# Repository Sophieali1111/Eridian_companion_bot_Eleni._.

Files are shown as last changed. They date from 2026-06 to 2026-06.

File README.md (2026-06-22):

# Eridian_companion_bot_Eleni._. 
WATCHED PROJECT HAIL MARRY and wanted my own Eridian bot ROCKY ! Meet Eleni [ torch in Greek].

# What is this?
A robot has 5 legs and at least 6 degrees of freedom, has a OLED showing cute faces, temp and custom information. Can be linked to a controller but also could just be a desk top buddy with automatic responses to temp change, tap on the head and time. Would make your life a bit more cozy and whimsy:)))

# Features
- move through terrain
- Cute animated bitmoji
- tempreture and moisture
- react to headpats
- remote controlable (via iphone)

# How to use
Eleni can connect to mobile with its microo controller(ESP32DEV),It can tell you weather stats such as tempreture, moister- from DTH 22 modoule, and also tell you time, date, weekday via OLED screen. Screen switches to the diffrent stats with a headpat (touchpad mounted on top). Eleni expresses emotion with OLED animated face she is pretty cute ^_^ .She can move around a lot of places up and down terrain, You can kindly ask(control) her with a remote on your phone or hard code her to do certain things.

# Why  ?
Well I really liked the movie project hail marry and i understand that everyone really likes it but i really felt somthing when rocky said to grace "Grace say Grace will die. Rocky fix. Grace go home,"[started bawling  my eyes out:(] So as you do i wanted to make a little rocky just mine, to "fist my bump".I have always also wanted my own robot companion, stupid but in all the scifi movies they have a superintellegent robot friend eg. tars interstella.Make your personal eridian(alian robot)! to keep you company and add a bit more whimsy to your life 

# How to build ?
go to  ( https://github.com/Sophieali1111/Eridian_companion_bot_Eleni._./blob/main/how_to_make.md )

# Zine page 
PROJECT (5)

# BOM
| Product name | Product discription | Product link | product unit price (AUD) | Product amount(AUD) | Product application in project | shipping cost  |
|---|---|---|---|---|---|---|
| ESP32 development board | a powerful low-cost and highly integrated microcontroller widely used for Internet of Things (IoT) projects. It features built-in Wi-Fi and Bluetooth capabilities a dual-core processor and multiple GPIO pins for connecting sensors motors and displays. | https://www.aliexpress.com/item/1005008796158734.html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 | 10.25 | 1 | This micro controller connects to the servos touchboard and OLED screen. with the output pins | 3.02 |
| polymer Lithium Ion Battery (LiPo) 3.7V 1500mAh | a thin lightweight and rechargeable power source commonly used in low-drain portable electronics and microcontroller projects (like Adafruit Feathers). It provides a nominal 3.7V output and holds a capacity of 1500mAH about 5.5 WHS | https://www.aliexpress.com/item/1005008347608135.html?src=google | 8.02 | 1 | This battery powers all the electronics components in the robot it is hooked to the tp4056 battery charges and has a good compacity | 3.4 |
| TP4056 Charging Module with Battery Protection | a compact dual-function electronic board designed for safely managing single-cell 3.7V lithium-ion or lithium-polymer batteries | https://www.aliexpress.com/item/1005005237080994.html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 | 0.21 | 1 | the charging moduole to charge the lithium battery | 3.51 |
| Capacitive Touch Sensor | Capacitive touch sensors are advanced input devices that register touch by detecting changes in electrical capacitance caused by a conductive object such as the human body | https://core-electronics.com.au/capacitive-touch-sensor-red.html | 1.95 | 1 | This senser will the input part into the robot and can trigger some fuctions output by the OLED and servos | 1.714 |
| 9g micro servo | an extremely compact lightweight and affordable motor used in small-scale robotics RC planes and DIY electronics. Weighing only 9 grams it typically provides up to 1.6 of torque and offers 180-degree rotation | https://core-electronics.com.au/feetech-fs90-1-5kgcm-micro-servo-9g.html | 5.36 | 10 | 6 degrees of freedom given by these servos and the 5 legs 2 servos on each leg | 1.714 |
| jumperwires | 10cm male-to-male jumper wires. Pre-terminated with an assortment of colors these 30 AWG wires are perfect for prototyping and connecting between breadboards and female headers. | https://zaitronics.com.au/products/jumper-wire-10cm-male-to-male-40pcs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 | NA | Own at home | the jumper wires connect the diffrent electronics components | 0 |
| OLED | a compact monochrome display widely used in DIY electronics and microcontrollers (like Arduino and Raspberry Pi Pico). It features a \(128 \times 64\) pixel resolution delivers excellent contrast with true blacks and uses I2C or SPI interfaces for easy integration | https://core-electronics.com.au/ssd1306-oled-white-pre-soldered.html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 | 6.7 | 1 | the OLED provides a output for expression and information for exp tempreture  weather and googly eyes | 1.714 |
| AAA battery |  a small cylindrical single-cell dry battery | https://www.officeworks.com.au/shop/officeworks/p/j-burrows-aa-batteries-8-pack-jbbty0aap8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 | 3 | need 4 but sells in budles of 8 | used to power servos sit in battery box | 0 |
|  Toggle Switch 3Pins Straight Feet Handle | High 5mm Spacing: Ensures stable and secure PCB mounting for reliable performance.3-Pin Configuration: Simplifies wiring and enhances compatibility with common circuit layouts.3A 250V Rating: Provides safe and efficient power control for various electronic devices.SS12D10/SS12D06 Model: Standardized toggle switches suitable for a wide range of applications.Straight Feet Handle Design: Offers easy installation and improved accessibility on circuit boards. | https://www.aliexpress.com/item/1005009993277549.html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 | 1.9 | 1 needed but sells in bundels of 10 | This is so the battery isnt running all the time and also acts as a saftey feature | 3.72 |
| DHT 22 | The DHT22 is a basic low-cost digital temperature and humidity sensor. It uses a capacitive humidity sensor and a thermistor to measure the surrounding air and spits out a digital signal on the data pin (no analog input pins needed). | https://www.aliexpress.com/item/1005010283810231.html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 | 4.61 | 1 | To measure the tempreutre and humidity of where it is do this so that it can start to give warning or tips to open the windows or turn of airconditioner  | 1.37 |
| 10k resistor | a standard general-purpose component used in digital electronics to ensure an input pin maintains a stable voltage (HIGH) when no other signal is active | https://www.jaycar.com.au/10k-ohm-0-5-watt-metal-film-resistors-pack-of-8/p/RR0596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 | 2.75 | 4 needed but sold in packs of 20 | use in robot to stablise voltage and signal on DHT 22 and OLED | 1.714 |
| battery box 4*AA | an enclosed plastic container designed to hold four AAA batteries in a series configuration | https://core-electronics.com.au/4-aaa-battery-holder.html | 4.25 | 1 | Powers 10 servos | 1.714 |
| 5V 3A Boost Converter Module 3.7V to 5V Step-Up for 18650 Lithium Battery DIY Power Bank 90% Efficiency | This is a small DC - DC boost module that integrates a PFM DC-DC boost control chip. It can convert a 0.9 ~ 5v power source to standard 5V making it capable of supplying power to an Arduino microcontroller and other small electronic devices that use a 5v input. The maximum output current is up to 500 ~ 600 mA. There are two power input ports PH2.0 and KF235-3.81-2P which are compatible with DFRobot's 3.7 V lithium battery. | https://core-electronics.com.au/dc-dc-boost-module-5v.html | 6.6 | 1 | needed to up to the 5v pin to esp or else would have to goto either 3n3 pin which wouldnt work if hooked up to the 5v then need a step up converter | 2 |
| SUBTOTAL | | | 55.6 | | | 25.59 |
| Total: 81.19 | | | | | | |

# Wiring 
Features an esp32 dev board and charges on a 3.3 charging board with a lipo battery and a step up powering components - 10 micro servos, OLED display, temp/Humidity sensor, touch sensor and also some resistors, schottky and a capacitor. seen by wiring diagram below
- rough diagram wiring idear(do not reference pins off this)

- wiring diagram 
circuit (4)

# CAD






Link to elenie assem- https://cad.onshape.com/documents/7f5fa5713a86b606455b3bf3/w/7087e430869ee173fcb78bb9/e/d070c0009b7c71805278058f
Link to leg assem- https://cad.onshape.com/documents/7348645cd8dd215efcb64763/w/6fcbcbdc9c87f3b11f2a5ccc/e/03a8affa70bfcf8abb9d1197

# Firmware 
- go to ( https://github.com/Sophieali1111/Eridian_companion_bot_Eleni._./blob/main/Firm%20ware%20/firmware )
- refrences and liabaries used go to                                                                                                                       ( https://github.com/Sophieali1111/Eridian_companion_bot_Eleni._./blob/main/references/libraries%20%2B%20inspo%20%2B%20acknowledgement )

# PCB 
project doesnt require pcb

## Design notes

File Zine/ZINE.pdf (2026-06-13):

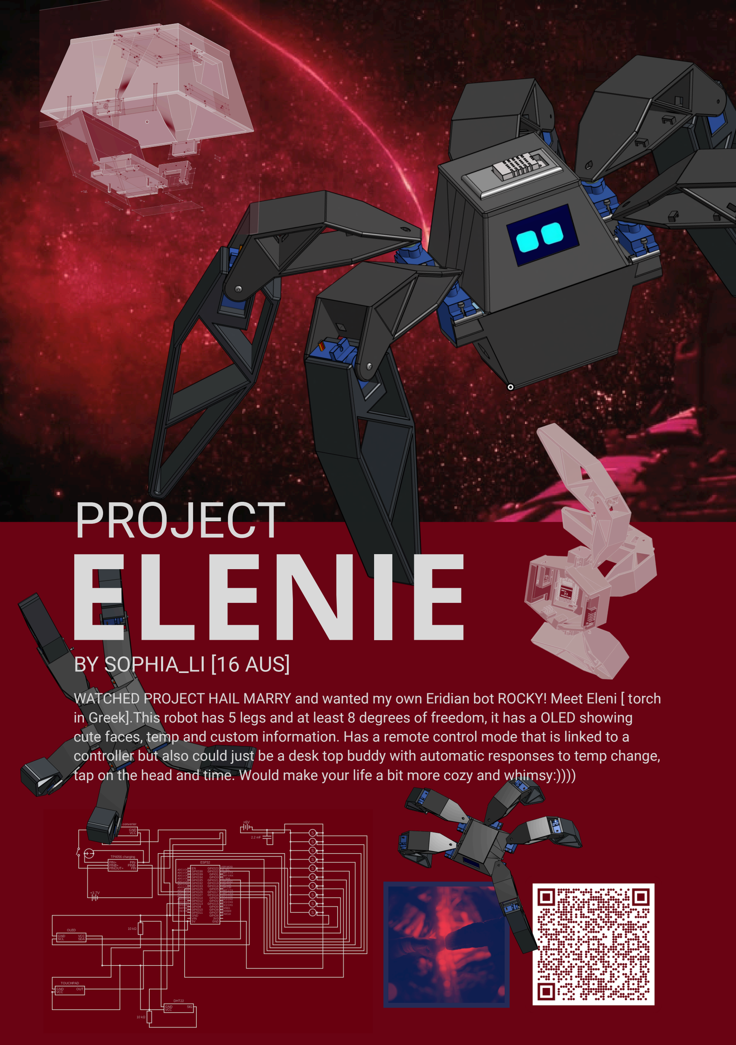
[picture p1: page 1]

# PROJECT

E

## BY SOPHI

L

## A_LI [16 A

E

US]

# NIE

WATCHED PROJECT HAIL MARRY and wanted my own Eridian bot ROCKY! Meet Eleni [ torch in Greek].This robot has 5 legs and at least 8 degrees of freedom, it has a OLED showing cute faces, temp and custom information. Has a remote control mode that is linked to a controller but also could just be a desk top buddy with automatic responses to temp change, tap on the head and time. Would make your life a bit more cozy and whimsy:))))

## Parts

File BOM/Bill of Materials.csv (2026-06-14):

Part | Description | Link | Unit Price (AUD) | Quantity | Cost | Shipping Cost (per vendor)
Battery Box | Battery Box 4x AAA. Power for servos. | https://core-electronics.com.au/4-aaa-battery-holder.html | 4.25 | 1 | 4.25
Touch Sensor | HW763 Touch Sensor | https://core-electronics.com.au/capacitive-touch-sensor-red.html | 1.05 | 1 | 1.05
Boost Converter | 5V 600mA Boost Converter | https://core-electronics.com.au/dc-dc-boost-module-5v.html | 6.6 | 1 | 6.6
Motor | 9g Micro Servo | https://core-electronics.com.au/feetech-fs90-1-5kgcm-micro-servo-9g.html | 4.76 | 10 | 47.6
Resistor | 10kΩ Resistor | https://core-electronics.com.au/resistor-10k-ohm-025-watt-pth.html | 0.85 | 5 | 4.25
Display | 0.96" OLED Display | https://core-electronics.com.au/ssd1306-oled-white-pre-soldered.html | 6.7 | 1 | 6.7 | 6.8
Charging Module | USB-C 5V 1A TP4056 Charging Module | https://www.aliexpress.com/item/1005005237080994.html | 0.22 | 1 | 0.22
Lipo Battery | 3.7V 1500mAh LiPo Battery. Power for sensors, display, and microcontroller. | https://www.aliexpress.com/item/1005008347608135.html | 11.7 | 1 | 11.7
Microcontroller | ESP32-S3 Dev Board Microcontroller, Pre-soldered pins | https://www.aliexpress.com/item/1005008796158734.html | 5.86 | 1 | 5.86
Toggle Switch | Toggle Switch | https://www.aliexpress.com/item/1005009993277549.html | 2.22 | 1 | 2.22
Temperature Sensor | DHT-22 Temperature and Humidity Sensor | https://www.aliexpress.com/item/1005010283810231.html | 2.62 | 1 | 2.62 | 12.15
Motor Battery | 1.5V AAA Battery | https://www.officeworks.com.au/shop/officeworks/p/j-burrows-aa-batteries-8-pack-jbbty0aap8 | 3 | 1 | 3
Jumper Wires | Jumper Wires | https://zaitronics.com.au/products/jumper-wire-10cm-male-to-male-40pcs | 3.1 | 1 | 3.1 |  | ALREADY HAVE
 |  |  |  | Subtotal | 99.17
 |  |  |  | Total AUD | 118.12
 |  |  |  | Total USD | 83.22

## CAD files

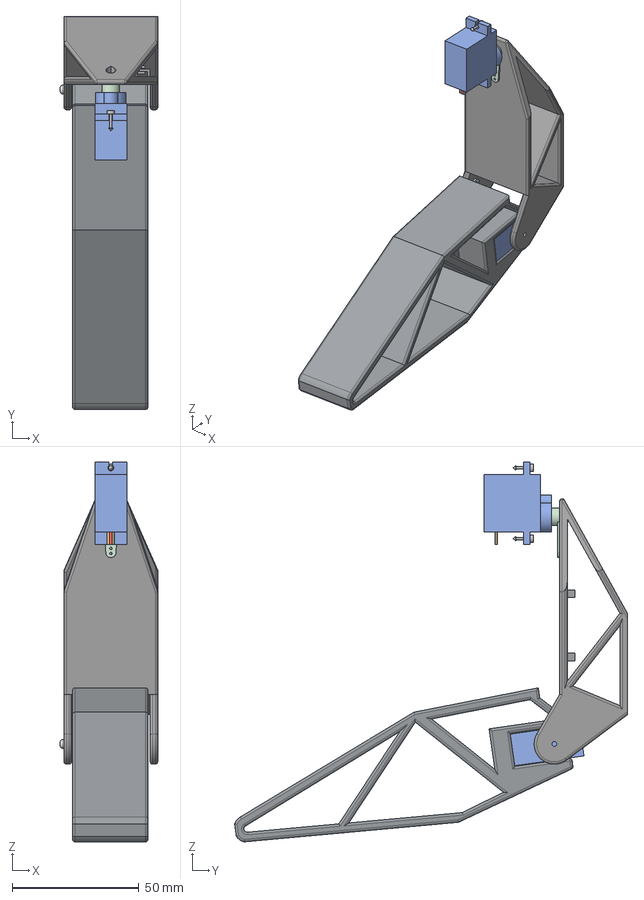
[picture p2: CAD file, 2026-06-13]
CAD/Leg_Assembly.step
38.5 x 155.0 x 149.8 mm
servo arm single x 2

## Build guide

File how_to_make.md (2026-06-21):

# Mainbody
-> 3D printed 
  -legs
  -top lid 
  -bottem lid
  -anything in grey really on the cad
  


  
# electronic components 

all brough online and shipped in can refrence the BOM including : 
- ESP32 development board
- LiPo battery 3.7V 1500mAh
- TP4056 charging module
- Capacitive touch sensor
- 9g micro servos ×10
- OLED SSD1306
- AAA batteries
- Toggle switch
- DHT22 sensor
- 10k resistors
- Battery box 4×AA
- 5V boost converter
- Jumper wires (owned)
# mounting 
- servos
  leg 3d print has a slot for the wings that come with the servos and then the bolt is bolted through the hole into fromthe 3D print into the servo side
  
  
  
  
  

- DHT22
  3d printed slot and then 3d printed lid with guilds and friction/ gravity 
  
  
  
  

-OLED
  3d printed part in main and also a little tab to hold (separte part)it inplace there is a removed bit to let the pins come through aswell 
  
  
  
  

-esp32 dev
  3D printed slots on the side on the sobot so just plop it in 
  
  

- lipo battery
  at the bottem of the case with a little lid put in battery then slide lid on
  
  
  

-charging module TP
  3d printed on top of the lid but a slightly more complex mechnism also has a removed part to plug usb
  
  
  

-batterie box
  in a battery box this mounting is lowkey smart so on the side s i extruded this little like shelfs so it kind sits in the middle of everything(blue box is battery box)
  
  
  
  

-Toggle switch
  Pretty self explanitory just a lid and an extrude to flip the switch
  
  
  
  

-5V boost converter
  mounting on the top with a like slot and a slide in stop
  
  
  

  From steps above assemble all electronics parts the follow the wiring diagram below and wire the electronics 
  circuit (4)

after doing steps above mount electrionics using the diagram below 
circuit (4)

Finally slide the lid together it should just be a click in and start working with the firmware

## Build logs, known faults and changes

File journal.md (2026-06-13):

# Project 001 Eleni  — Journal Export

- Exported at: 2026-06-13T13:28:33Z
- Project ID: 2864
- Entries: 47

## Entry 1
- ID: 4843
- Author: studing.sophia
- Created At: 2026-05-02T02:36:50Z

### Content

figured out what we are going to do for this project- name , fuctions , requirment, subsystems , rough idea of materials. Companion robot that brings you joy and can help with basic tasks[time, temperature , funny jokes]
Requirements:
look like rocky from project hail marry 
Be able to respond to audio and auto  
Artificial intelligence
Have at least 8 degrees of freedom 

There is two parts kinda to it 
Moving part (MP)
Responding part (RP)

Electronics + materials needed MP
Servos 
Main board control board 
3d print
Battery
Bluetooth module 
Step-down Module 

Electronics + materials needed RP
Bluetooth module 
Step-down Module 
Output module 
Input module 
Processer 
Somhow connect to ai?(got to learn have no idea how that works )
i am a bit scared but thing i can do it 
WhatsApp Image 2026-05-02 at 10.44.19 AM.jpeg
WhatsApp Image 2026-05-02 at 10.44.20 AM.jpeg
WhatsApp Image 2026-05-02 at 12.24.18 PM.jpeg
WhatsApp Image 2026-05-02 at 12.28.23 PM.jpeg

## Entry 2
- ID: 5102
- Author: studing.sophia
- Created At: 2026-05-02T12:21:21Z

### Content

I figured out what to prototype +this session is a lot of researching, what parts to buy planning and stuff
WhatsApp Image 2026-05-02 at 10.17.12 PM.jpeg
Stage 1 Prototype 

 Prototype robotic leg *1 use can be used at home 
Figure out the cad and design for the leg, Code it to ensure that it can move, figure out how much weight it can bare therefore how much weight the robot can be. 
Material/ resources CAD- onshape: arduino uno, bread board, electrical wires, 3D printer, code - arduino IDE 
Prototype the audio output input 
Make a input and output, that can control servos and can save input in a the computer 
Material/ resources:
https://www.instructables.com/Speech-Controlled-Robot-Easy-Version/ , Auduino IDE,Arduino Nano,hc 06 bluetooth module, battery output 
Prototype the artificial intelligence
Learn and prototype how to have local ai respond to audio and output back to robot. 
Material/ resources: Chatgpt(train ai model) or arduino uno Q 
Crayon cad 
Sketch the design how the robot looks - then after other sub prototypes do final CAD 

## Entry 3
- ID: 5277
- Author: studing.sophia
- Created At: 2026-05-03T12:55:31Z

### Content

Today was designing and failing, i have started to wonder if my CAD skills are as good as i think they are, I am learning design principles by blood and sweat. Failed had to restart, but ultimantly i think i have a design that will work. i have started a bit of a crayon cad figured out how the mounting will go. the first servo will be positioned so that the shorter side is parrell to the group this is mounted to the first part of the leg and gives it freedom the rotate 180 degrees releative to the  y axis . and the second will mount from the main robot body and have a connecting peice allowing the leg to move left and right. This will be 3D printed and prototyped. Next need to figure out the code for servo, finish the crayon cad get a review improve apon it then do some 
Screenshot 2026-05-03 225245.png
Screenshot 2026-05-03 225322.png
Sign out day 2 :)))) i hate onshape just kidding i am going crazy from cad . This is teaching me quite a bit, ig failure really is the mother of success 

## Entry 4
- ID: 5417
- Author: studing.sophia
- Created At: 2026-05-04T11:34:05Z

### Content

Finished CAD part of the protypes, looked at how to do the codding for the servos, which is what i am going to do next session Arduino IDE. 

Screenshot 2026-05-03 225245.png

## Entry 5
- ID: 5420
- Author: studing.sophia
- Created At: 2026-05-04T12:20:22Z

### Content

I Figured out which parts i have at home that i can use for the prototyping 
WhatsApp Image 2026-05-04 at 10.15.54 PM.jpeg

started a system for refrencing 
WhatsApp Image 2026-05-04 at 10.15.52 PM.jpeg
started a system for buying new parts which is just a check list
WhatsApp Image 2026-05-04 at 10.15.53 PM.jpeg
Found some code i could use for prototyping 
Also the last journal i uploaded the wrong picture that is not finished its this one

Screenshot 2026-05-04 221939.png

Feeling good 
:))))

## Entry 6
- ID: 5706
- Author: studing.sophia
- Created At: 2026-05-06T08:55:53Z

### Content

WhatsApp Image 2026-05-06 at 6.48.17 PM.jpeg

In this session i fixed the cad to make sure that the part would 3D print, it was quite the hassel, looked at wiring, and 3D printed the part ext found partst
WhatsApp Image 2026-05-06 at 6.48.16 PM.jpeg
WhatsApp Image 2026-05-04 at 10.15.54 PM.jpeg
WhatsApp Image 2026-05-04 at 10.15.53 PM.jpeg

## Entry 7
- ID: 5888
- Author: studing.sophia
- Created At: 2026-05-07T12:46:56Z

### Content

Big CAD entry there was like 45 minutes that couldnt be logged for some reason this will be logged by problems 

problem 1 - dumb did calculations wrong ended up the parts where the servos sat was too long

problem 2 the legs clash into each other when is certain positions fix 1 - impliment hard stops fix 2 cut a bit off of the legs, fix 3- move them all out a bit , Fix 4 map it wider
 FIXED using 4 and 3
problem 3 the part where the servo connects to the legs is only connected by 4mm 3D print, Different material? 
Problem 4 the mounting on the servos to the parts are funky what parts ad what nut is that size that would fit ?

protoyping finds:
3 servos can run on one battery?
no unfortanatly the circuit didnt work the prototype kinda failed 
WhatsApp Image 2026-05-07 at 10.40.55 PM.jpeg
WhatsApp Image 2026-05-07 at 10.43.01 PM.jpeg

## Entry 8
- ID: 6252
- Author: studing.sophia
- Created At: 2026-05-09T12:10:51Z

### Content

Today is designing / developing electronics and code :)))
I think that next step is probs to design a pcb or to learn and design it on a soldered board but that should be after the design is a bit more finalised and put in cad More :)))) 
it took quite a bit cuz i needed to learn how to do it and i couldnt figure out why it didnt work as well as i wanted it too. The circuit needs to be more simplfied. the CAD can get some more work and the codding and audio input bit can have work put in as well. Also looking at different parts what is needed and what i have what i need to put into parts list 
Screenshot 2026-05-09 204651.png
Screenshot 2026-05-09 204740.png
Also did reasearch on another computor for parts and put into a google docs . Also fixed parts of the CAD that had problems before 
leart about PCB thats all sign outttt
WhatsApp Image 2026-05-07 at 10.43.01 PM.jpeg

## Entry 9
- ID: 6574
- Author: studing.sophia
- Created At: 2026-05-11T11:30:28Z

### Content

more cad yayyyyyyyyyyyy. fixed small things for example the ledges on the servo mounts that were poking out. and the wiring holes. made a place for the auduno to sit and had work done on electrionics, yayy signing out 
Screenshot 2026-05-11 212924.png
Screenshot 2026-05-11 212913.png

## Entry 10
- ID: 7055
- Author: studing.sophia
- Created At: 2026-05-14T11:31:03Z

### Content

added a battery pack and looked at how to cad wires its so complicated tbh, idk if the wiring is needed in the cad doc but i will forsure leave mounts for wiring and have a final check for it . I have also decided to add a led screen to project certain things to make the robot look cuter which is what is going to be done in the next sesh


## Entry 11
- ID: 7065
- Author: studing.sophia
- Created At: 2026-05-14T12:25:03Z

### Content

there is this cute little idear sketch, 
WhatsApp Image 2026-05-14 at 10.22.09 PM.jpeg
i found a way to do it the little screen, it will be a esp32 connected to a OLED and with another chargable battery. the project will also have a button to switch screens such as temp and weather i found a prohjecct that somone else is working on and took inspo from that 
Screenshot 2026-05-14 220312.png

## Entry 12
- ID: 7246
- Author: studing.sophia
- Created At: 2026-05-15T12:41:30Z

### Content

today try and figure out the lid for the robot functions has to house the touch module mount to the main body and have the OLED. stable, reliable , and easy to mout 
First sussed out a snap fit-toomuch material needed and while it is accessable it isnt really what this design needs 
a thread and twist- bit hard to master and understand 
decided the leg need a bit of changing nvm i think change alot of the work 

Screenshot 2026-05-15 224103.png

## Entry 13
- ID: 7340
- Author: studing.sophia
- Created At: 2026-05-16T00:10:50Z

### Content

today try and figure out the lid for the robot functions has to house the touch module mount to the main body and have the OLED. stable, reliable , and easy to mout 
First sussed out a snap fit-toomuch material needed and while it is accessable it isnt really what this design needs 
a thread and twist- bit hard to master and understand 
decided the leg need a bit of changing 

Screenshot 2026-05-16 100413.png

Screenshot 2026-05-16 100516.png

Screenshot 2026-05-16 100634.png
Screenshot 2026-05-16 100610.png

## Entry 14
- ID: 7406
- Author: studing.sophia
- Created At: 2026-05-16T12:28:25Z

### Content

Redesigned the egs today so we can fit the leg and also have more room to move the logs and more freedom . thought quite a bit about how to mountthe lid
and yes i lowkey decided on tapping 3d print ik ik but i have faith it will work. but further on i ight change it to be a snap fit might 
we will see and see CNC get it? nvm not funny gang i swear i was quite productive this sesh also bolts used are gona be m3 i add a 0.5 extra material to tap into might add more later dont know . 

i fixed the cad it use to be different parts but now it is the same part , it took a bit bc the constaints all broke now it is one part
Screenshot 2026-05-16 201146.png
Screenshot 2026-05-16 221227.png
i put the cad in folders xcuz it was getting messy
i put latches on
Screenshot 2026-05-16 222141.png
what it looks like rn
Screenshot 2026-05-16 222653.png
okok byeeee

## Entry 15
- ID: 7600
- Author: studing.sophia
- Created At: 2026-05-17T12:38:08Z

### Content

figure out the mounting for the screen on the top decided i was gona do two partsthe top bit justslides the think in place , and the the bottem beite you can take off and thenshove a peice in with like little round tubes you will get it once its like fully done , took quite a bit just to think of where everything would go 
Screenshot 2026-05-17 223721.png

## Entry 16
- ID: 7602
- Author: studing.sophia
- Created At: 2026-05-17T12:55:09Z

### Content

Screenshot 2026-05-17 225122.png
like so the other part is coming in like that into the holes its has a chamfer to fit better and i am hoping the tollerance be fine but at the end will do a tollerance check + cad check with somebody like a friend or smth idk to check everything could be manufactored. but that is all i just had to finish that part so my hands dont itch yayyyy got a lot more to do tmr do all the other parts that the top needs and the day after do all the wiring possibily 

## Entry 17
- ID: 7776
- Author: studing.sophia
- Created At: 2026-05-18T11:41:38Z

### Content

today there is more cad to do wowow , first strarted putting in cad and mounting for the touch pad ttp223, it sits on the top of the robot beneath 3 mm of polycarb or 3d print which does not conducted electricity

now figgure out the micro computer can not put it horrozoally tried that and it pokes through thelid. 
now thats donw liek so 
Screenshot 2026-05-18 204023.png
i added all the parts exept the battery do next time and also i think i need to add a extra part at the bottem
Screenshot 2026-05-18 213814.png
Screenshot 2026-05-18 204023.png
Screenshot 2026-05-18 212755.png
Screenshot 2026-05-18 212818.png
Screenshot 2026-05-18 213814.png

## Entry 18
- ID: 7954
- Author: studing.sophia
- Created At: 2026-05-19T12:19:12Z

### Content

I finalised the rough cad today, there is so much change and improvments i already see that i can make tmr i will look at what to do moving forw and make a BOM and other parts that appertanly are needed for this submition. 
Screenshot 2026-05-19 221550.png
Screenshot 2026-05-19 221329.png

## Entry 19
- ID: 8149
- Author: studing.sophia
- Created At: 2026-05-20T13:37:43Z

### Content

i changed the appearnce of the thing, like the cool colors, 
i looked through what i needed to do to get on and documentation for it kinda ran in my head about how many more hours i need and the time spans for it , not extreamlly productive but just for a tiny bit i promise. then i took a look at the wiring and through the legs, it is gona go 
Screenshot 2026-05-20 232053.png
through the part and into the little loops to other motor wires which will be shoved into the little gap between the lid yay. 
Screenshot 2026-05-20 232226.png
what i need to do up next for next spesj complete self cad review(make the tiny like parts to hold the motors mount the motors whatever, tolerances, mounting, space  ext) 
just downloaded blender to render the cad, and possibily learn it.:)))
also read through a lot of the documentation today, bravo on that 

## Entry 20
- ID: 8300
- Author: studing.sophia
- Created At: 2026-05-21T11:43:22Z

### Content

today i made a start and made a github account, wrote discription to it, and started my personal CAD review, 
I am now going to list what i have fixed and reasons + explanations:
- mounting the motor small TPU parts 
Screenshot 2026-05-21 194515.png
these two clash and also the fact that this charging port is getting blocked by that leg i tried solving this by putting the charging port up more and ext but i it still looks like it clashes and is blocked now i am looking into more solutions 
Screenshot 2026-05-21 203823.png
omg there is this mini one of an esp 32 this way i can just decrease the space uptop omggg
Screenshot 2026-05-21 213918.png
this part so next sesh just gona finish altering with that and make a BOM !!!

## Entry 21
- ID: 8388
- Author: studing.sophia
- Created At: 2026-05-21T23:00:22Z

### Content

Ok so today we fixed the problem that the charging port is right in front of the leg and obviousily cannot charge- did this by switching to a esp 32 super mini, changing the position of the touch pad , we added a peice that would hold the piece in by friction . we also found a lot of problems :)) but thats ok we are gona fix it , so here are problem lists :
-part on the OLED not interferces with the esp mounting
- the friction mounts might need to be improved apon maybe some smart snapp fit dk 
- the battery interfere with the botten bit 
and the large batteries interfer with the mounting 
Screenshot 2026-05-22 085311.png
Screenshot 2026-05-22 085354.png
Screenshot 2026-05-22 085539.png

## Entry 22
- ID: 8459
- Author: studing.sophia
- Created At: 2026-05-22T11:49:55Z

### Content

for this sesh started out by fixing the clash between the big like batteries and the OLED screen, by extending the top lif or making the top lid 2 mm taller yes thats all it needed

put things into folders and organised 



now imma log out 

## Entry 23
- ID: 8632
- Author: studing.sophia
- Created At: 2026-05-23T10:23:10Z

### Content

Design change :
- have one lithium battery replace the two chunky ones at the bottom .
-Run it all on one battery which is chargeable 
- change to esp 32 replace the esp 32 supermini and the Arduino board 
why is this you ask:
well first it is less space needed and more compact it requires less weight and the mounting and lid do not have to be opened that much. this means we can have a more solid compound and usefull design saving money at the same time as being more simpleisit 
but that just means a lot more cad but oh well thats life
and also had a look at requirments and the bomb reqirments 
HAD a look at the esp 32 dev board looks like could work has enough output pins, and need to find a charging moduel thatcant boost 3.5 up to 5 v 
the battery should run 5 v across the entire robot since all the components could work at 5


## Entry 24
- ID: 8642
- Author: studing.sophia
- Created At: 2026-05-23T12:19:58Z

### Content

Today wrote a BOM 
The design is now upgraded because of cost and packaging resons, the part in the past was a aduino and an esp32 mini now is an esp 32 dev bord becausse why have two when you can power with one and also much cheaper. also had to chage the tp to one that has a step up to 5 v as thats the only one the servos can sun on and if i want to ake it so that one battery powers the entire robot that has to be at 5 v
Screenshot 2026-05-23 221527.png

## Entry 25
- ID: 8852
- Author: studing.sophia
- Created At: 2026-05-24T12:31:01Z

### Content

added a column in the BOM called application in project 


suppressed everything now gotta redo all the iner cad :)))
design choices are gona be listed below 
- the lithium battery is gona be mounted at the top, why? because it is convinent and um if it blows up well no that much gets damadged, just kidding hahaha sorry not funny no because if it gets hot the hot air travels up and has somwhere to go and not mess arounf with other electronics :) nvm scrap that its goona be at the bottem easier mounting and also the touchpad needs somwhere to go ok done 
- next part is the esp 32 dev board probs gona sit right on top of the battery 

## Entry 26
- ID: 9075
- Author: studing.sophia
- Created At: 2026-05-25T09:58:24Z

### Content

I am looking at how to mount the esp 32 i was thinking on the bottem but now looking at it i am think on the back side , ok its done
i thought i needed a battery mount but relised i put the battery mount at the bottem already and wha i need is a tp charging place ontop , now have to recad:(((
i just looked at the mounting it is fixed now but there is a problem i cannot find a cad of the electrical component that i have just found:((  
i might change somthing i think the reviews for the TP charging is really bad and unstable i will change back to the original charging board but add a step up module 

the part studio cad is all done now next i just have to assemble and finlise parts of cad eg. wiring considerations cadding , efficaiantcy 


## Entry 27
- ID: 9330
- Author: studing.sophia
- Created At: 2026-05-26T10:37:56Z

### Content

keepthe cadding going
i thinkthis is the art of cadding there is always more problems, unbelievable ik, here are some that i found while assembling which is what we are doing today
- the charging holeisnotcorrectdimention
- it has to have more support, as it has to stay together,  and hold in place quite well while it has the charging port being plugged in :( and its difficuilt mounting
-couldnt find a cad of the electronics of the step up modoule 
Now  most the cad is done and the drilling proccess begins the cad revies i start by doing a cad review myself then i will go find some frineds and after maybe my frc mentor but we will see
i can already see some things that should be fixed but here is the current version the blue on the top is just for better visability 
Screenshot 2026-05-26 195549.png
okso sophias cad review starts here
- 

this is ment to be a tpu 3d print but this is kinda weird mounting , so what i thing should do is add a extrapart on the top and make it a snap fit
same with this one 

change it so the lid can become a snap fit
-all these have no electrical wiring gaps need to do that 
same with these there - the tpp , module step up, andthetouch pad 


Ya so in this session have finished the assembily just need to contact people and finish my own cad review edits
Had a look on what istill had to do and the planning how do do it in the 26-7  hours i still have left ;000
the  firmwear, the readme and the little page thing :)))

## Entry 28
- ID: 9882
- Author: studing.sophia
- Created At: 2026-05-28T11:28:53Z

### Content

Today still fixing cad :))

the robot is gona look like rocky i am gona use air dry clay   and aliminium to mimic the texture 



clip just made

reference off the 3D print

## Entry 29
- ID: 9903
- Author: studing.sophia
- Created At: 2026-05-28T13:23:17Z

### Content

having a look at making the zine now 
inspo 

this vibe 



Refrences  inspo


i am gona spend a bit on my zine and before that i need to finlise my cad write what i am gona write and have the firmware and problems fixed 
o also for the pictures the electrical wiring diagram 

## Entry 30
- ID: 10114
- Author: studing.sophia
- Created At: 2026-05-29T11:22:22Z

### Content

OKKK today kinda tying things together did a bit of everything so first worked on the zine, it took long time cuz wanted every like font and page and color to look correct to me but we get to this point

rendered the part then cropped a part so it has that coming out of screen effect have the project hail marry astrophage as a part and the different shades of red . 
some work on wiring diagrams i dont like how they did it so i am going to hand draw it with a3 paper next sesh

have a bit of work on cad 
and worked on readme and git hub a bit 


## Entry 31
- ID: 10124
- Author: studing.sophia
- Created At: 2026-05-29T12:22:27Z

### Content

Worked more on ripo in github have big long think about what why how? 
am a bit worried about the software firmware part of things 

more change on the zine:))) 

Next sesh figure out wiring and also have a cad review ooooo before then put in the switch part 

## Entry 32
- ID: 10368
- Author: studing.sophia
- Created At: 2026-05-30T11:15:22Z

### Content

Added a switch part today it acts as  saftey safe gaurd and also just to same electricity. 
![image.png](/user-attachments/blobs/redirect/eyJfcmFpbHMiOnsiZGF0YSI6MjM1MDMsInB1ciI6ImJsb2JfaWQifX0=--a629b73cae3fec80763b7a020b63864bcf159e

ya and my laptop kinda broke down so i was searching how to fix my fan 

## Entry 33
- ID: 10371
- Author: studing.sophia
- Created At: 2026-05-30T11:38:15Z

### Content

Couldnt find a step up modoule cad so just did a rough cad for dimentions, and put it in i also just mated the boards properlly bc could see it was intervering with things 



## Entry 34
- ID: 10643
- Author: studing.sophia
- Created At: 2026-05-31T12:30:10Z

### Content

1 updated bom cuz added a new component the dht 22 which is To measure the tempreutre and humidity of where it is, do this so that it can start to give warning or tips to open the windows or turn of airconditioner 
2 i put the mounting of that in cad 

Didnt turn out too bad, 
3 i also did some work on the zine 

looks pretty cool in my oppnion. 
4 the electronics 
WhatsApp Image 2026-05-31 at 9.54.08 PM.jpeg
First drafted on paper (need to do final draft though )
Screenshot 2026-05-31 201711.png
made online 
5 to make it more realistic gona use airdry clay to mimic the rock textrure on the outside of the 3D print 
WhatsApp Image 2026-05-31 at 9.54.09 PM.jpeg
robot assem (4).png
robot assem (3).png
rendered cad 

For the next sesh need to get a cad reviw esta 5h together to finish all cad and upgrade dont know how and what though 
also need to write the read me better and more spicific 2h esta
and then work on firmware 4 h esta 

outside layer.png

## Entry 35
- ID: 10871
- Author: studing.sophia
- Created At: 2026-06-01T11:29:06Z

### Content

I just ran a cad review with a frined and we found some problems 
- the esp board is currently in a  position where it is inaccessable 
- the the parts at the bottem can just be held by tabs because then it can be accessable 
- the servos could probably mount inside the case to have a cleaner look
- add a cylinder to the part servo to leg 
- make it so that parts are actually printable 
-


## Entry 36
- ID: 10872
- Author: bowie
- Created At: 2026-06-01T11:31:25Z

### Content

Reworked the wiring diagram.
Made the power circuitry work

Added schottky diode to prevent servo current spikes from damaging/browning out esp32.
The battery might need a bit more capacity and the power delivery circuitry might need to be reworked. The pins don't exactly match the pinout on the esp32 because I had trouble finding a consistent pinout, but I checked that there are enough of each pin type to get all the connections that are needed.

## Entry 37
- ID: 11024
- Author: studing.sophia
- Created At: 2026-06-02T01:53:03Z

### Content

Today did more of the read me 


also read more into the reqirments , and what i shoudl do future on
what to improve apon the read me 
looked at others read me to see what i shoudl do 
also ested around to a new zine
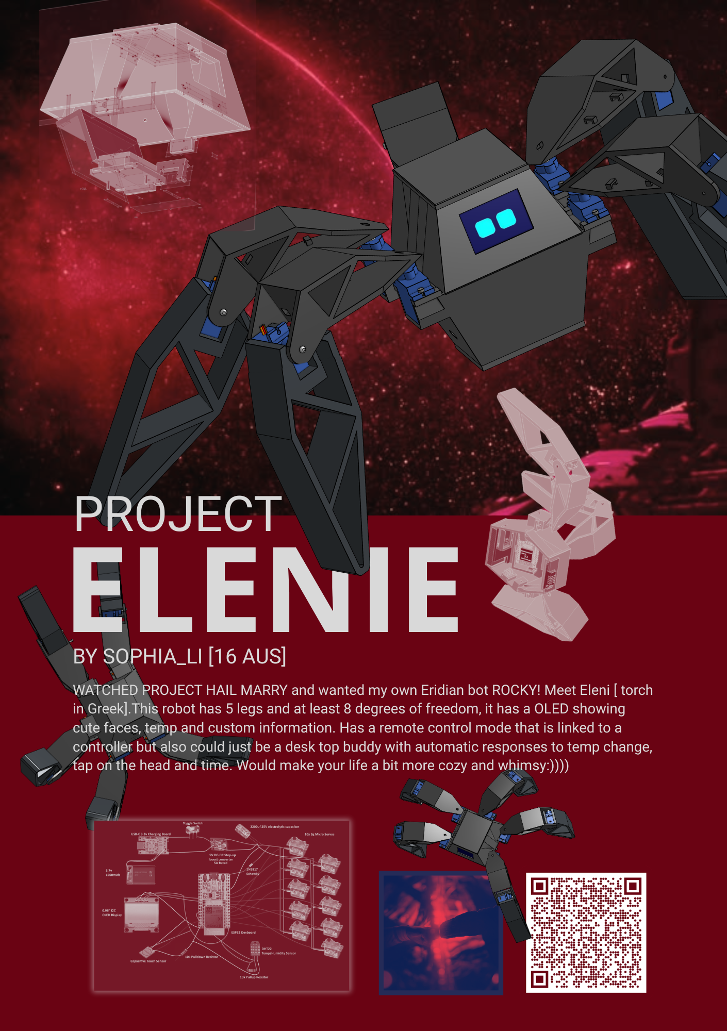
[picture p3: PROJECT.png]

for wiring i saw a lot of others did a online ver so as you do i tried to learn how to do it 

everything should be done exept not connected some pins to the esp but i tried researching and have no idea how to do so so my plan is to ask my friend once his school ends how to do it 


## Entry 38
- ID: 11368
- Author: studing.sophia
- Created At: 2026-06-03T12:32:02Z

### Content

First problem not being able to get to wiring the bottem bit i just removed two holes so the wires could come through 

second is the esp board no being able to get to its pins to solve this just making it clipped to the board 

tried to finish the electrical wiring, figure out the pinouts and how doable it is 
from here on it is more finishing up or refining work , get people /frineds /chat to check the work and then refine it 
o also have to get a start on the firmware 

that is end of journel today :) so tired 

- ID: 11830
- Author: studing.sophia
- Created At: 2026-06-05T13:12:48Z

### Content

ok today i asked for some review from a teacher what he said was to change the electrical a bit because the lipo battery cannot run the servos and it will not be enough to work . therefore change it so that they are powered sepretaly with a 6v battery 

so today we are going to do that today figure out electronics and draw a rough diagram 
here

and now there is the elecronics pin ver of it so what has changed a few parts

i am gona look through it added to bom and to new cad. and please have a look at firm ware and check off boxes 

## Entry 40
- ID: 11987
- Author: studing.sophia
- Created At: 2026-06-06T04:06:34Z

### Content

Today we updated the BOM and added components such as the resistor AAAbatteries new battery box, and deleted the step up modoule . also updated the zine. and the githud  because there is the new wiring diagram and stuff. and then started cadding to put the battery box in the cad v

in like so pretty cool way to mout it tbh bc it need to take outeasy and all the walls are either ocupied or dont have enough space to house it good because can still get to electronics at the bottem 


o and also the mounting for the top slider and thought about how to do it so made the part that slides in slightly thinner can bend more and also the ball at the bottem a bit larger that is one thing that might need a bit more work on maybe 


## Entry 41
- ID: 12010
- Author: studing.sophia
- Created At: 2026-06-06T07:45:35Z

### Content

Ok so , TOday i fixed up some cad including the mounting the pins the slots. and overall did more cad cuz onshape is driving me crazy 

And then also updated the zine again becase the elctrical wiring changed agian . and then also updated bom onto github and did more for github read me 

also i now have a refrences docuent that i def should have started building from the start not the end :((((



## Entry 42
- ID: 12290
- Author: studing.sophia
- Created At: 2026-06-07T14:08:58Z

### Content

Today was a big firmware day foun dlots of libaries refrences and ext. asked cluade to be my personal teacher because i honstly do not know what to do software wise . therefore i read  manule for aduino. Also my friend had a look at my wiring and apperently that is preety wrong and have to do again so that is maybe what i am going to do . made a google doc for refrences btw and also ooks at a sample that the bot gave me. i Understand a little of phython its gona be pretty challenging tbh :(( i am kinda lost 



## Entry 43
- ID: 13434
- Author: studing.sophia
- Created At: 2026-06-12T10:20:32Z

### Content

-review esp 32 pinouts 
- check sepcific esp pinout conflicts / review data sheet 
- double check scl and sda pins i^2 c 
- servo motor mounting to leg, need to not rely soley on one bolt have to have wings that servos come with 
- add fillets to every thing looks nicer more fuctional 
- the touch pad mounting lid has to not come from the side it already is because it interfers with the dht 
- NAME ALL PARTS
- fix cad: get rid of RED
- add holes for pins - touch sensor (but checkall)
- check esp32 exact model, upadte cad
- add more tolerance around ALL pins
- tollerence to everything - especially the battery  mounting ext. 
circuit (1).png

## Entry 44
- ID: 13451
- Author: studing.sophia
- Created At: 2026-06-12T12:34:30Z

### Content

Looked at esp pinout changed a few pinouts and the wiring, My circuit is good but one thing the tp is charging at 3.7 v but can either be plugged into a 5 or 3.3 so it has to be boosted up to five there for have to add a boost component to make sure everything works ok. i reaserached what part to put in and also put it in bom 


## Entry 45
- ID: 13605
- Author: studing.sophia
- Created At: 2026-06-13T01:09:51Z

### Content

finlised circuit there was following problems fixed 
- insert step up module 
[TP4056 Output]  ───►  [5V Boost Converter]  ───►  [ESP32 & Sensors Power Rail]
1. Disconnect the Existing Power LineLocate the wire coming out of the TP4056 PINOUT+.Cut/Disconnect this wire from the rest of the circuit (where it currently splits to feed the ESP32 5V pin, OLED VCC, Touchpad VCC, and DHT22 VCC).2. Wire the Boost Converter Input (Low Voltage Side)Connect TP4056 PINOUT+ directly to the VIN (+) input of your 5V Boost Module.Connect TP4056 PIN- (or your common ground rail) to the GND (-) input of your 5V Boost Module.3. Wire the Boost Converter Output (Stable 5V Side)Connect the 5V / VOUT from the Boost Module (either via the USB port or directly soldered pads) to the power line feeding:ESP32 5V pinOLED VCCTouchpad VCCDHT22 VCC
- fixed esp pins 
-Fix the Switch Placement (Move to Input)
-Combine your 5V Power Lines (VOUT / VCC)
-Boost Converter 5V Output ──► Connects to ALL of the following together:ESP32 5V pinOLED VCCTouchpad VCC

circuit (3).png

mounting the stepup it was really hard cuz didnt know where to mount it however its good cuz we gona mount on the top of it  
also trying to get the servo leg to mount 

the wing 

## Entry 46
- ID: 13638
- Author: studing.sophia
- Created At: 2026-06-13T04:43:22Z

### Content

oknow the servo is mounted with the wings that the servos came with 


filletedeverything legs body ext to make it look more slick
legs


i can see the endddd now i just need give more space to pins for mounting then i can bedone with cad  
andthis touch pad didnt fit ontop so 

oh no there is still lots of cad:((( oh well more work ig 

## Entry 47
- ID: 13717
- Author: studing.sophia
- Created At: 2026-06-13T13:28:01Z

### Content

ok this is just a rlly long sesh of hackthon fishing it basically 
yayyyy done i think i hope 
today done lots of firm ware added a lot to the git hub retro including all new folders -cad refrencing , manufacuring , bom, zine , and firm ware lots of firm ware i am so tired be up too late 




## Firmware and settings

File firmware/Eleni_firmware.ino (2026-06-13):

//==============================================================
//Project : Eleni - Eridian COmpanion robot 
//Author : sophia 
//Date : 13/06/2026

//what eleni does:
// moves around makes cute faces and outputs info from screen such as temp, humidity and maybe other things depending on how well the bluetooth and wifi part work 
// components: 
// - esp32 DEV board
// - OLED 
// - DHT 22 temp/ humidity sensor 
// - 10*9g servos 
// - Lipo batter + TP4056 charger + step up 
// - captive touchsensor 
// refrences 
//   Wiring inspiration:
//     https://github.com/EDISON-SCIENCE-CORNER/DESKBUDDY-1.0
//   Design inspiration:
//     https://www.youtube.com/watch?v=1UDsWkcQZhc
//   OLED eye animation reference:
//     https://github.com/playfultechnology/esp32-eyes
//   DHT22 library:
//     https://github.com/adafruit/dht-sensor-library
//   Servo library:
//     https://docs.arduino.cc/learn/built-in-libraries/software-serial/
//   ESP32 board package:
//     https://raw.githubusercontent.com/espressif/arduino-esp32/...
//   Adafruit SSD1306 library (via Arduino Library Manager)
//   ESP32 pinout reference:
//     https://randomnerdtutorials.com/esp32-pinout-reference-gpios/
//   Project inspiration — Project Hail Mary (Andy Weir):
//     Rocky the Eridian companion
// ================================================================
// --LIBARIES--
#include <Wire.h>                // I2C 
#include <Adafruit_GFX.h>        // Graphics basic 
#include <Adafruit_SSD1306.h>    // Graphics oled
#include <DHT.h>                 // humidity sensor 
#include <ESP32Servo.h>          // servos
#include <WiFi.h>                // connect to wifi
#include <WebServer.h>           // servo
// --- Pin Definitions ---

// Touch sensor
#define TOUCH_PIN    T0   // GPIO4 - capacitive touch on head

// DHT22
#define DHT_PIN      15   // GPIO15 - temp/humidity data wire
#define DHT_TYPE     DHT22

// OLED
#define OLED_WIDTH   128
#define OLED_HEIGHT  64
#define OLED_ADDR    0x3C // fixed I2C address for SSD1306

// Servos - 5 legs x 2 servos each = 10 total
int SERVO_PINS[10] = {
  32,  4,   // Leg 1 - servos 1, 2
  16, 17,   // Leg 2 - servos 3, 4
  18, 19,   // Leg 3 - servos 5, 6
  25, 26,   // Leg 4 - servos 7, 8
  27, 23    // Leg 5 - servos 9, 10
};

// --- Objects ---

Adafruit_SSD1306 display(128, 64, &Wire, -1);// oled wide + lengh

DHT dht(15, DHT22);// sensor 

Servo servos[10];// def amout of servos legs 
// --- Variables ---
float temperature = 0.0;   // current temperature from DHT22
float humidity = 0.0;      // current humidity from DHT22
bool isWalking = false;      // is Eleni currently walking
unsigned long lastSensorTime = 0;  // last time sensor was read
unsigned long lastBlinkTime = 0;   // last time Eleni blinked
unsigned long lastTouchTime = 0;   // last time head was patted
void setup() {
  Serial.begin(115200); // starts communication with your computer for debugging

  // 1. Initialise OLED
  display.begin(SSD1306_SWITCHCAPVCC, OLED_ADDR);
  display.clearDisplay();
  display.display();

  // 2. Start DHT22
  dht.begin();

  // 3. Attach all 10 servos
  for (int i = 0; i < 10; i++) {      
    servos[i].attach(SERVO_PINS[i]);
  }

  // 4. Sleep position - knees spread out
  for (int i = 0; i < 10; i++) {
    servos[i].write(130);               // what angle for spread knees?
  }
  delay(2000);                           

  // 5. Stand up - neutral position
  for (int i = 0; i < 10; i++) {
    servos[i].write(90);               // what angle for neutral standing?
  }

  // 6. Happy wake up face
  // [we will fill this in when we do the face functions]

  Serial.println("Eleni is awake!");
    // 7. Show temperature on OLED for 10 seconds
  display.clearDisplay();
  display.setTextSize(2);          // text size 2 = medium
  display.setCursor(0, 0);         // start at top left
  display.print("Temp:");
  display.print(temperature);              // what variable holds temperature?
  display.print("C");
  display.display();
  delay(10000);                      // how many milliseconds is 10 seconds?

  // 8. Show humidity for 10 seconds
  display.clearDisplay();
  display.setCursor(0, 0);
  display.print("Humidity:"); 
  display.print(humidity);p
  display.print("%");
  display.display();
  delay(10000);                      // same as above
}

void loop() {
  
  server.handleClient();  //checks if handled client

  checkTouch();           // checks touch sensor if activated
  
  readSensors();          // checks sensors 
  
  updateDisplay();        // updated the disply 

  delay(20);              // small pause so ESP32 doesn't run too fast and crash
 void checkTouch() {
  
  // check if touch sensor is activated
  if (touchRead(TOUCH_PIN) < 40) {
    
    // 1. Happy face
    // [we will fill this in with face functions later]

    // 2. Dog bow stretch - front two legs forward and down
    servos[0].write(30);  // leg 1 hip - forward
    servos[1].write(60);  // leg 1 knee - down
    servos[2].write(30);  // leg 2 hip - forward
    servos[3].write(60);  // leg 2 knee - down
    delay(3000);            // hold the stretch - how long?
    
    // 3. Back to standing
    for (int i = 0; i < 10; i++) {
      servos[i].write(90); // neutral standing
    }

    // 4. Show time on OLED
    display.clearDisplay();
    display.setTextSize(2);
    display.setCursor(0,0);
    display.print("Time:");
    display.display();

    // update last touch time
    lastTouchTime = millis();
  }

  // if no headpat for 30 seconds → paranoid mode
  if (millis() - lastTouchTime > 30000) {  // 30 seconds in milliseconds?
    // [paranoid face + walk in circles]
  }

void readSensors() {

  // only read every 3 seconds so we dont overload the sensor
  if (millis() - lastSensorTime > 3000) {
    
    temperature = dht.readTemperature(); // read temp in celsius
    humidity = dht.readHumidity();       // read humidity %

    // update the timer
    lastSensorTime = millis(); // millis() gives current time in milliseconds

    // print to serial monitor for debugging
    Serial.print("Temp: ");
    Serial.println(temperature);   // which variable?
    Serial.print("Humidity: ");
    Serial.println(humidity);   // which variable?
  }
}
}
void updateDisplay() {

  if (temperature > 30) {
    display.clearDisplay();
    display.setTextSize(2);
    display.setCursor(0,0);
    display.print("Too hot!");
    display.print(temperature);
    display.print("C");
    display.display();
    // [hot face - fill in with face functions later]

  } else if (temperature < 10) {
    display.clearDisplay();
    display.setTextSize(2);
    display.setCursor(0,0);
    display.print("Brrr!");
    display.print(temperature);
    display.print("C");
    display.display();
    // [cold face - fill in with face functions later]

  } else {
    // [normal face - fill in with face functions later]
  }
}
void walkForward(int steps) {
  isWalking = true;

  for (int s = 0; s < steps; s++) {
    // Phase 1 - front group lifts and swings forward
    servos[0].write(110); // leg 1 hip forward
    servos[1].write(65);  // leg 1 knee lift
    servos[4].write(110); // leg 3 hip forward
    servos[5].write(65);  // leg 3 knee lift
    servos[8].write(110); // leg 5 hip forward
    servos[9].write(65);  // leg 5 knee lift
    delay(120);

    // Phase 2 - front group lands
    servos[0].write(110);
    servos[1].write(90);
    servos[4].write(110);
    servos[5].write(90);
    servos[8].write(110);
    servos[9].write(90);
    delay(60);

    // Phase 3 - back group lifts and swings
    servos[2].write(110);
    servos[3].write(65);
    servos[6].write(110);
    servos[7].write(65);
    delay(120);

    // Phase 4 - back group lands
    servos[2].write(110);
    servos[3].write(90);
    servos[6].write(110);
    servos[7].write(90);
    delay(60);
  }

  // back to standing
  for (int i = 0; i < 10; i++) {
    servos[i].write(90);
  }

  isWalking = false;
}
}

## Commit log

2026-06-06 Update BOM - Sheet1 (2).csv
    [BOM - Sheet1 (2).csv]
2026-06-13 Create bom
2026-06-13 Update bom
2026-06-13 Create cad files
2026-06-13 Update and rename cad files to cad files links
2026-06-13 Create making + mounting + manufacturing
2026-06-13 Update and rename making + mounting + manufacturing to making + mounting + manufacturing.md
2026-06-13 Update making + mounting + manufacturing.md
2026-06-13 Rename cad files links to cad_files_links.md
2026-06-13 Rename BOM - Sheet1 (6).csv to BOM.csv
    [BOM.csv]
2026-06-13 Rename Leg assem step.step to Leg_Assembly.step
    [Leg_Assembly.step]
2026-06-13 Rename Elenie body assem step.step to Body_Assembly.step
    [Body_Assembly.step]
2026-06-13 Rename BOM - Sheet1 (7).csv to BOM.csv
    [BOM.csv]
